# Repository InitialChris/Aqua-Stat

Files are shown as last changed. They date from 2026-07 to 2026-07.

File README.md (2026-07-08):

<!-- TOC -->

Aqua≈Stat

---

Automatic Water Level Controller based on STM8 MCU.

<!-- TOC start -->
- [Overview](#overview)
- [Level Sensors](#level-sensors)
- [Tuning](#tuning)
- [Schematic](#schematic)
- [Hardware](#hardware)
- [Enclosure and Front Panel](#enclosure-and-front-panel)
- [FSM Logic](#fsm-logic)
    * [System Status LED Indicators](#system-status-led-indicators)
- [Firmware Architecture](#firmware-architecture)
    * [Portability](#portability)
- [Building](#building)
<!-- TOC end -->

<!-- TOC -->
## Overview
Aqua ≈ Stat is a water level controller designed for swimming pools and water tanks. 

It utilizes two external capacitive sensors to monitor the upper and lower limits, ensuring complete electrical isolation by avoiding direct contact with the water. The optimal water level is reached using calibrated dead-reckoning timers.

The entire control logic runs on an ultra-low-cost 8-bit STM8 microcontroller.

<!-- TOC -->
## Level Sensors

Capacitive sensors are preferable because they avoid direct contact between the electronics and the water, preventing electrical hazards or corrosion. However, other sensors like standard mechanical float switches can also be used to detect the water level.

Each sensor features a trimmer to adjust its sensitivity. They must be calibrated to ensure the output (indicated by the built-in LED on the sensor) reliably toggles when water is detected.

The two sensors must be placed far enough apart to prevent excessively frequent fill and drain cycles.

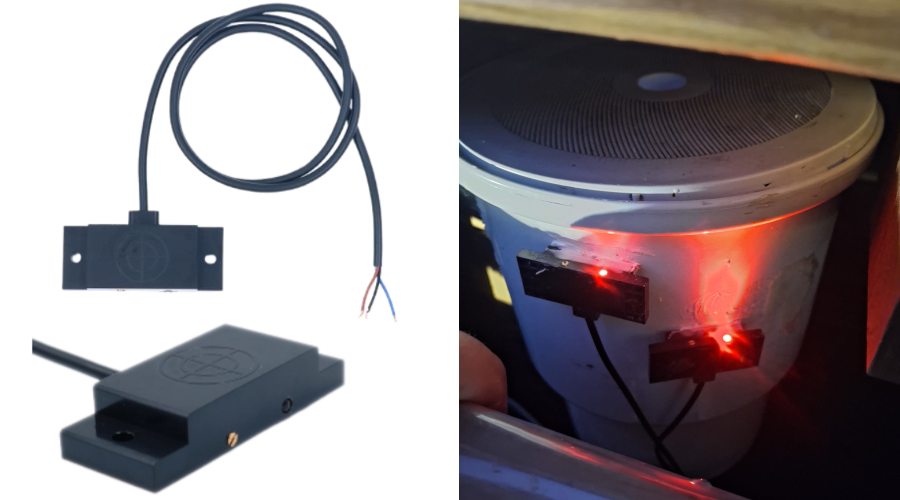
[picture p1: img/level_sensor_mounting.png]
Level sensor mounting


<!-- TOC -->
## Tuning
The configuration file located at [`firmware/include/config.h`](firmware/include/config.h) contains the parameters that must be tuned for the system to operate correctly. 

Since the system does not use a third middle sensor, the optimal level is reached by timing the drain and fill cycles after crossing a sensor threshold.

* **`T_FILL_MS`**: Time required for the water level to rise from the low sensor to the ideal setpoint (halfway between the two sensors).
* **`T_DRAIN_MS`**: Time required for the water level to fall from the high sensor to the ideal setpoint.
* **`T_WAIT_MS`**: Cooldown time enforced when an overshoot occurs (e.g., the water reaches the high sensor while the fill timer is still running). It prevents rapid, infinite fill/drain loops.
* **`T_SENSOR_DEBOUNCE_MS`**: Debounce filter duration (typically 3-5 seconds). It reduces system reactivity, making it immune to false triggers caused by water ripples or minor fluctuations on the sensor surface.

<!-- TOC -->
## Schematic
Schematic

<!-- TOC -->
## Hardware
The prototype circuit is built on a perfboard; currently, there are no plans to design a dedicated PCB.

For the MCU, a low-cost STM8S003F3P6 breakout board is used. The onboard LDO voltage regulator is removed to allow the microcontroller to be powered directly at 5V from the main circuit.

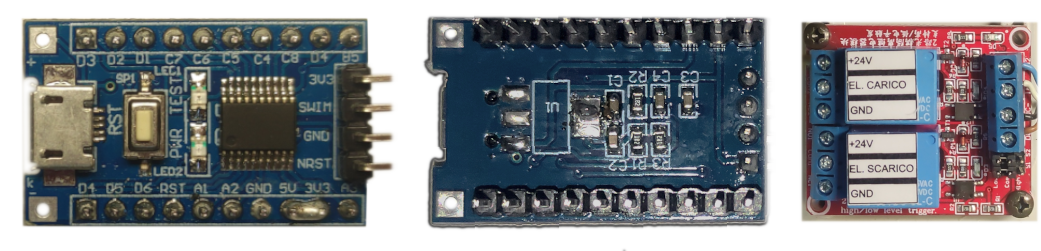
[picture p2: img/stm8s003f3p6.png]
STM8S003_Breakout


The system drives a standard 2-relay module to control the load (solenoid valves or pumps). The board's jumpers must be set to "L" (Low-Level Trigger) so the channels activate when the BJT driver outputs are pulled to ground.

If the system is powered by a high voltage supply (e.g., 24V), it is highly recommended to use a DC-DC step-down converter instead of a classic LM7805 linear regulator. The current drawn by a single active relay is enough to significantly heat up a linear regulator, requiring a bulky heatsink. Alternatively, you can choose a relay board with a coil voltage that matches the main power supply, bypassing the 5V regulator entirely for the heavy load, just ensure the relay board's optoisolators or logic inputs can still be safely triggered by the 5V logic of the STM8.

<!-- TOC -->
## Enclosure and Front Panel
The electronics are housed in a waterproof outdoor junction box.

To display the system status on the front panel without compromising the enclosure's waterproof rating, the light emitted by the 7 SMD LEDs soldered on the perfboard is guided to the outside using 1.7mm optical fiber strands.

The front panel graphics were designed in Inkscape, printed on a standard A4 sheet, laminated with wide transparent tape for weather resistance, and attached to the box using double-sided tape. 

To allow the optical fibers to pass cleanly through the laminated paper sheet, a custom mini hole punch was made by sharpening the edges of a small steel tube using a drill and files.

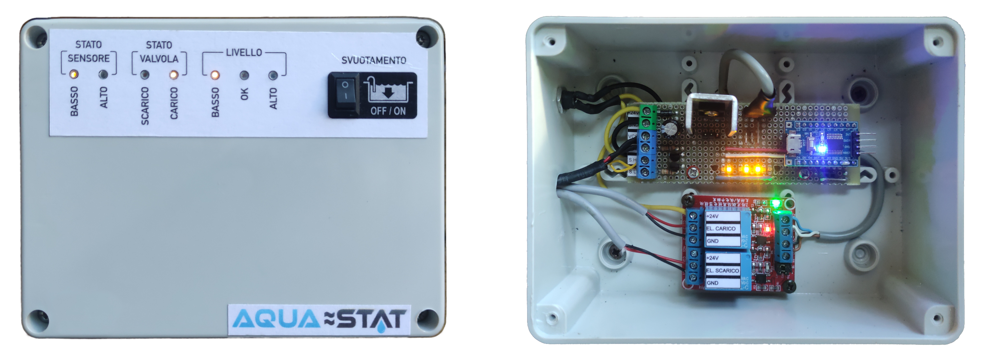
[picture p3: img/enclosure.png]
Front Panel and Prototype


<!-- TOC -->
## FSM Logic
The algorithm is powered by a Finite State Machine (FSM) that manages the water cycle through the following states:

* **Startup** (`RESET_STATE`): Upon power-up, the system waits on standby until the sensor readings pass the debounce filter. If the water level is already between the two sensors at startup, it assumes the optimal state (`IDLE_STATE`).

* **Filling** (`FILL_STATE` & `FILL_TIMER_STATE`): If the water drops below the lower sensor, the fill relay is activated. When the level rises above the lower sensor, a timer starts and continues filling until the ideal level is reached.

* **Draining** (`DRAIN_STATE` & `DRAIN_TIMER_STATE`): If the water rises above the upper sensor, the drain relay is activated. When the level drops below the upper sensor, a timer starts and continues draining until the ideal level is reached.

* **Anti-Loop Protection** (`WAIT_HIGH_STATE` & `WAIT_LOW_STATE`): If the upper sensor is triggered during the timed filling phase (overshoot), the system enters a blocking wait state to prevent an infinite fill/drain loop. If this occurs, the physical distance between the sensors must be increased, or the timer parameters in the code must be reduced. The same logic applies during the draining phase. 

* **Hardware Error** (`ERROR_STATE`): If the system detects the upper sensor as active and the lower one as inactive, it identifies a physical paradox or hardware fault. It immediately locks the relays and enters an error state. The FSM automatically recovers only when the readings become physically plausible again.

* **Manual Override** (`MANUAL_DRAIN_STATE`): Activating a physical switch bypasses the entire FSM logic, forcibly keeping the drain relay active to completely empty the pool for maintenance.

<!-- TOC -->
### System Status LED Indicators

| Header | FSM State | Description |
|---|---|---|
| DRAIN | `DRAIN_STATE` | Level is above the high sensor. Drain valve is active. |
| DRAIN_TIMER | `DRAIN_TIMER_STATE` | Level dropped below the high sensor. Timed drain to reach setpoint. |
| IDLE | `IDLE_STATE` | Target level reached. Water is stable between the two sensors. |
| FILL_TIMER | `FILL_TIMER_STATE` | Level rose above the low sensor. Timed fill to reach setpoint. |
| FILL | `FILL_STATE` | Level is below the low sensor. Fill valve is active. |
| MANUAL | `MANUAL_DRAIN_STATE` | Manual override switch is closed. Drain valve is active. |
| ERROR | `ERROR_STATE` | Hardware fault: High sensor is active while low sensor is not. |
| RESET | `RESET_STATE` | Booting / Waiting for the first valid sensor reading. |
| WAIT_LOW | `WAIT_LOW_STATE` | Dropped below low sensor during drain. Cooldown to prevent looping. |
| WAIT_HIGH | `WAIT_HIGH_STATE` | Rose above high sensor during fill. Cooldown to prevent looping. |

<!-- TOC -->
## Firmware Architecture
The firmware is organized into the following components:

* [**`config.h`**](firmware/include/config.h): System configuration parameters. Timing parameters and FSM configuration.
* [**`pin_map.h`**](firmware/include/pin_map.h): Hardware GPIO definitions and mapping.
* [**`fsm.h`**](firmware/src/fsm.h): The core Finite State Machine logic.
* [**`sensors_debouncer.h`**](firmware/src/sensors_debouncer.h): A combined software debouncer for the two level sensors.
* [**`systick.h`**](firmware/src/systick.h): Hardware timer implementation to emulate the standard `millis()` function for time-tracking.
* [**`stm8s_conf.h`**](firmware/src/stm8s_conf.h): Peripheral library configuration (optimized to include only the strictly necessary drivers to reduce flash memory footprint).
* [**`main.c`**](firmware/src/main.c): Main execution loop, hardware initialization, GPIO assignments, and FSM ticking.

<!-- TOC -->
### Portability
While this firmware was explicitly developed in C for the STM8S003 on PlatformIO, the core logic is hardware-agnostic and easily portable to other 8-bit (e.g., Arduino/ATmega328P) or 32-bit (e.g., STM32) microcontrollers. 

To port the project:
* The `systick.h` module can be entirely omitted (or bypassed) if your target framework already provides a native `millis()` function (such as the Arduino core). 
* The FSM logic remains untouched. You will only need to adapt the hardware-specific GPIO reads and writes to match your chosen microcontroller.
* The structure of `main.c` must be adapted to the execution model of the target framework. For example, if you are using the Arduino core, the standard C `main()` function and its infinite `while(1)` loop must be split into the standard `setup()` and `loop()` functions

<!-- TOC -->
## Building
To compile and flash the project:

1. Open the [`firmware`](firmware) folder using the [**PlatformIO**](https://platformio.org/) extension in Visual Studio Code.
2. Install the STM8 platform framework when prompted by PlatformIO (if not already installed).
3. Adjust the system timing and configuration parameters inside [`config.h`](firmware/include/config.h).
4. Connect an [ST-Link](https://www.st.com/en/development-tools/st-link-v2.html) programmer to the STM8 SWIM interface and click **Upload** to flash the firmware.

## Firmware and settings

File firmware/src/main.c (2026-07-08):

#include "stm8s.h"
#include <stdint.h>
#include <stdbool.h>
#include "pin_map.h"
#include "config.h"
#include "systick.h"
#include "fsm.h"
#include "sensors_debouncer.h"

// Helper macro to set GPIO pin state based on a boolean value
#define GPIO_Set(port_pin, value)  ((value) == RESET ? GPIO_WriteLow(port_pin) : GPIO_WriteHigh(port_pin))

SensorsDebouncer sensors_debouncer;
FSM_Context_t fsm_context = {RESET_STATE, RESET_STATE, 0};
FSM_Output_t fsm_output = {false, false, false, false, false};

extern uint32_t millis(void);  // Forward declaration for the millis() function

void setupMCU();
bool readSwitchState();
void applyOutputToHardware(FSM_Output_t *output);


void main(void){
    setupMCU();
    sensorsDebouncer_init(&sensors_debouncer, T_SENSOR_DEBOUNCE_MS, ACTIVE_LOW_SENSORS);
    
    while(1){
        // Input handling
        sensorsDebouncer_update(&sensors_debouncer, (bool)GPIO_ReadInputPin(GPIO_SENSOR_LOW), (bool)GPIO_ReadInputPin(GPIO_SENSOR_HIGH));
        SensorLevel_t sensor_level = sensorsDebouncer_get(&sensors_debouncer);
        bool switch_state = readSwitchState();

        // FSM processing
        FSM_Input_t fsm_input = {sensor_level, switch_state};
        FSM_ComputeNextState(&fsm_context, &fsm_input);
        FSM_SaveState(&fsm_context);
        FSM_GetOutputForState(&fsm_context, &fsm_output);

        // Output handling
        applyOutputToHardware(&fsm_output);
    }
}

// Setup the microcontroller's clock, GPIO pins, and timer
void setupMCU(){
    // 16 MHz internal (HSI) clock
    CLK_HSIPrescalerConfig(CLK_PRESCALER_HSIDIV1);

     // Input configuration: no interrupt, enable pull-up for switch if active low
    GPIO_Init(GPIO_SENSOR_LOW,  GPIO_MODE_IN_FL_NO_IT);
    GPIO_Init(GPIO_SENSOR_HIGH, GPIO_MODE_IN_FL_NO_IT);
    GPIO_Init(GPIO_SWITCH,      ACTIVE_LOW_SWITCH ? GPIO_MODE_IN_PU_NO_IT : GPIO_MODE_IN_FL_NO_IT);

    // Output configuration: push-pull, low speed, initialize to inactive state
    GPIO_Init(GPIO_VALVE_DRAIN, ACTIVE_LOW_VALVES ? GPIO_MODE_OUT_PP_HIGH_SLOW : GPIO_MODE_OUT_PP_LOW_SLOW);
    GPIO_Init(GPIO_VALVE_FILL,  ACTIVE_LOW_VALVES ? GPIO_MODE_OUT_PP_HIGH_SLOW : GPIO_MODE_OUT_PP_LOW_SLOW);
    GPIO_Init(GPIO_LED_HIGH, ACTIVE_LOW_LEDS ? GPIO_MODE_OUT_PP_HIGH_SLOW : GPIO_MODE_OUT_PP_LOW_SLOW);
    GPIO_Init(GPIO_LED_MID,  ACTIVE_LOW_LEDS ? GPIO_MODE_OUT_PP_HIGH_SLOW : GPIO_MODE_OUT_PP_LOW_SLOW);
    GPIO_Init(GPIO_LED_LOW,  ACTIVE_LOW_LEDS ? GPIO_MODE_OUT_PP_HIGH_SLOW : GPIO_MODE_OUT_PP_LOW_SLOW);

    // TIM4 configuration: 1ms tick (16MHz / 128 / 125 = 1kHz)
    TIM4_TimeBaseInit(TIM4_PRESCALER_128, 124);
    TIM4_ClearFlag(TIM4_FLAG_UPDATE);
    TIM4_ITConfig(TIM4_IT_UPDATE, ENABLE);
    TIM4_Cmd(ENABLE);

    enableInterrupts();
}

// Read the state of the manual override switch applying debounce logic
bool readSwitchState(){
    static bool last_switch_state = false;
    static bool current_switch_state = false;
    static uint32_t switch_ms = 0;
    bool switch_state = ((bool)GPIO_ReadInputPin(GPIO_SWITCH)) ^ ACTIVE_LOW_SWITCH;

    if (switch_state != last_switch_state){
        switch_ms = millis();
    } else if (millis() - switch_ms > T_SWITCH_DEBOUNCE_MS){
        current_switch_state = switch_state;
    }

    last_switch_state = switch_state;
    return current_switch_state;
}

// Apply the computed FSM output to the hardware GPIO pins based on the active low/high configuration for valves and LEDs.
void applyOutputToHardware(FSM_Output_t *output){
    GPIO_Set(GPIO_VALVE_FILL,  output->valve_fill  ^ ACTIVE_LOW_VALVES);
    GPIO_Set(GPIO_VALVE_DRAIN, output->valve_drain ^ ACTIVE_LOW_VALVES);
    GPIO_Set(GPIO_LED_HIGH,    output->led_high    ^ ACTIVE_LOW_LEDS);
    GPIO_Set(GPIO_LED_MID,     output->led_mid     ^ ACTIVE_LOW_LEDS);
    GPIO_Set(GPIO_LED_LOW,     output->led_low     ^ ACTIVE_LOW_LEDS);

    // Prevent compiler optimization, for a strange reason the optimizer removes the last GPIO_Set() call.
    __asm__("nop");
}

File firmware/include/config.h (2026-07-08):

/*----------------------------------------------------------------------------
 * CONFIGURATION
 *----------------------------------------------------------------------------*/
#pragma once

/* User Configuration */

// Time required to fill the pool (from low sensor trigger to desired level)
#define T_FILL_MS               (22UL * 60UL * 1000UL)  /* 22 minutes */

// Time required to drain the pool (from high sensor trigger to desired level)
#define T_DRAIN_MS              (15UL * 60UL * 1000UL)  /* 15 minutes */

// Safety delay between cycles to prevent frequent sensor triggering
#define T_WAIT_MS               (60UL * 1000UL)         /* 60 seconds */

// Debounce time for water level sensors stabilization
#define T_SENSOR_DEBOUNCE_MS    (6UL * 1000UL)          /* 6 seconds */


/* System Configuration */

// Debounce time for the empty pool switch
#define T_SWITCH_DEBOUNCE_MS    (1000UL)    /* 1 second */

// Blink interval for the error signaling LED
#define T_ERROR_BLINK_MS        (500UL)     /* 500 milliseconds */
#define T_ANIMATION_MS          (250UL)     /* 250 milliseconds */

// Active low configuration for switches, sensors, valves, and LEDs
// If true, the corresponding hardware is considered active when the GPIO pin is low (0V).
#define ACTIVE_LOW_SENSORS   true
#define ACTIVE_LOW_SWITCH    true
#define ACTIVE_LOW_VALVES    false
#define ACTIVE_LOW_LEDS      true

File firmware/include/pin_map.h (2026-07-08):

/* ----------------------------------------------------------------------------
 * Pin mapping for the STM8S003F3P6 MCU
 * ---------------------------------------------------------------------------
 *                                  
 *                                    STM8S003F3P6
 *                         ┌───────────────────────────────┐
 *   GPIO_LED_HIGH (OUT) ──|  1 [PD4]    [USB]    [PD3] 1  |── GPIO_VALVE_DRAIN (OUT)
 *    GPIO_LED_MID (OUT) ──|  2 [PD5]             [PD2] 2  |── GPIO_VALVE_FILL  (OUT)
 *    GPIO_LED_LOW (OUT) ──|  3 [PD6]             [PD1] 3  |── PD1
 *                  NRST ──|  4 [RST]             [PC7] 4  |── PC7
 *  GPIO_SENSOR_LOW (IN) ──|  5 [PA1]             [PC6] 5  |── PC6
 * GPIO_SENSOR_HIGH (IN) ──|  6 [PA2]             [PC5] 6  |── PC5
 *                   GND ──|  7 [GND]             [PC4] 7  |── PC4
 *                   5V  ┬─|  8 [5V]              [PC3] 8  |── PC3
 *                       └─|  9 [3V3]             [PB4] 9  |── PB4
 *    GPIO_SWITCH   (IN) ──| 10 [PA3]             [PB5] 10 |── PB5
 *                         └───────────────────────────────┘
 *                                 O    O    O    O
 *                               NRST  GND SWIM  3V3
 * - 3.3V Regulator is bypassed
*/
#pragma once

// Inputs
#define GPIO_SENSOR_LOW     GPIOA, GPIO_PIN_1
#define GPIO_SENSOR_HIGH    GPIOA, GPIO_PIN_2
#define GPIO_SWITCH         GPIOA, GPIO_PIN_3

// Outputs 
#define GPIO_VALVE_FILL     GPIOD, GPIO_PIN_2
#define GPIO_VALVE_DRAIN    GPIOD, GPIO_PIN_3
#define GPIO_LED_HIGH       GPIOD, GPIO_PIN_4
#define GPIO_LED_MID        GPIOD, GPIO_PIN_5
#define GPIO_LED_LOW        GPIOD, GPIO_PIN_6
